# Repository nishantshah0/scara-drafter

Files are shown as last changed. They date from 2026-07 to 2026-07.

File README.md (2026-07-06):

# SCARA Drafter — a robot arm that draws CAD drawings

A 3D-printed SCARA robot arm that picks up a pen and drafts real CAD drawings
(DXF files exported straight from Onshape) onto A5 paper. Design a part in
CAD → hit export → a robot you built draws it in ink.

Built as a mechatronics internship portfolio piece. ~$160 CAD in parts;
every structural component printed on a Bambu P1S.

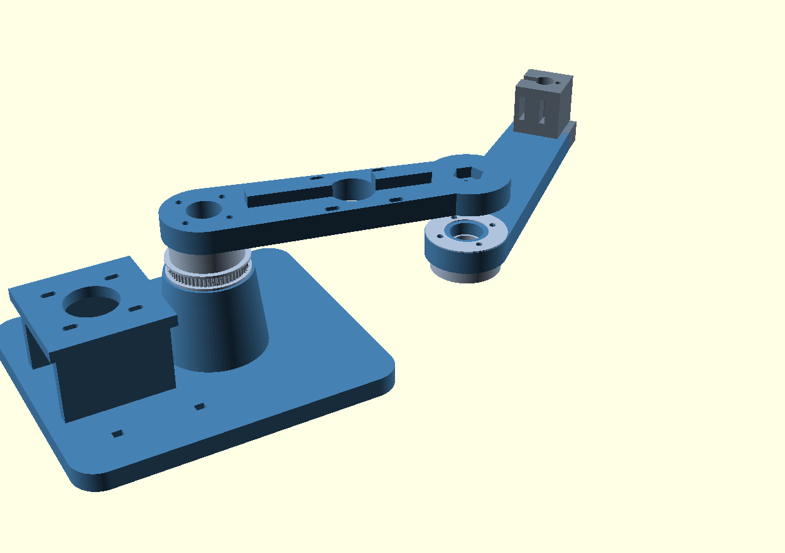
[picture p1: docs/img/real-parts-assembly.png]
Printable parts v1, assembled

*Printable parts v1 (OpenSCAD, [source](cad/scara-parts.scad)): base with shoulder tower
and motor platform, 60T pulley-hubs, both links, pen carriage. Belt center distance is
parametric pending measured belts (D9); tolerances pending the bearing coupon.*

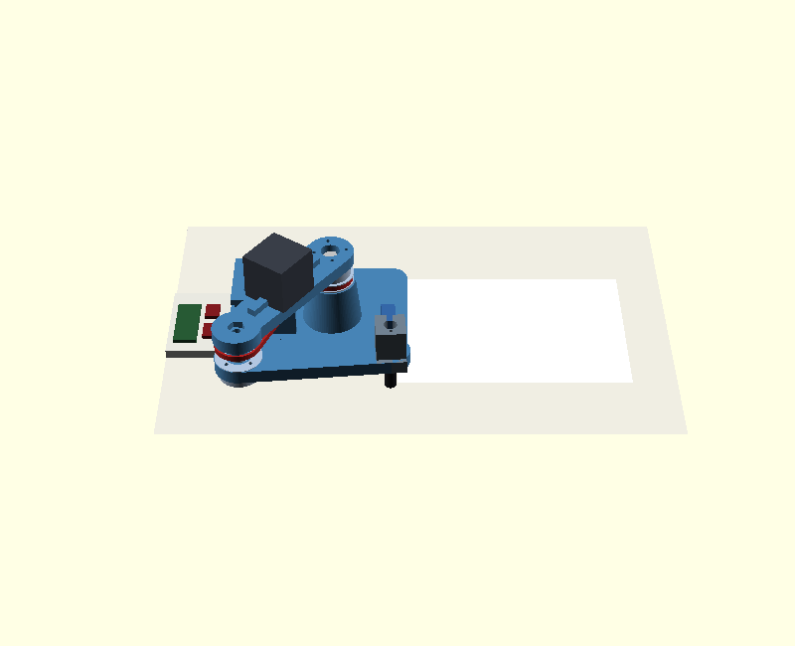
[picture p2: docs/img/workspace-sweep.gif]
Full workspace sweep, arm2/tower collision check

*Animated sweep across the entire usable A5 sheet (32 poses, real inverse-kinematics
solutions from [software/ik.py](software/ik.py) — not hand-picked). Verifies arm2 never
clips the base tower: [clearance_check.py](cad/clearance_check.py) computes the worst
case numerically (pen at the paper's near edge, arm folded to 156°) at **12 mm of
clearance**, run it yourself with `python cad/clearance_check.py`.*

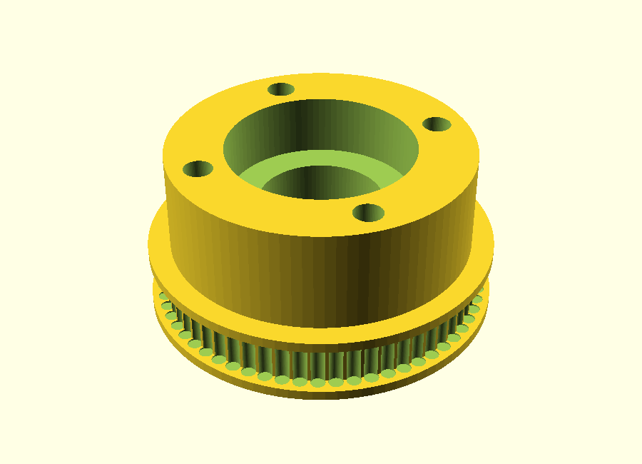
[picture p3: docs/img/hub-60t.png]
60T pulley-hub

*The heart of both joints: printed 60T GT2 pulley integrated with the bearing hub —
one part, printed twice, flipped for the elbow.*

## The demo loop

```
Onshape sketch ──export──▶ DXF ──parse──▶ toolpath ──inverse kinematics──▶
joint angles ──WiFi──▶ Pico W ──step pulses──▶ steppers ──belts──▶ pen on paper
```

Every arrow in that pipeline is something I built and can explain.

## Architecture

- **Topology:** SCARA — two rigid printed links swinging in a horizontal
  plane (gravity stays out of the drawing plane; precision comes cheaper),
  plus a micro-servo pen lift. ~130 mm links → covers an A5 sheet.
- **Actuation:** 2× NEMA17 steppers through printed GT2 belt reductions
  (~3:1) — reduction multiplies resolution and torque, and belt tension is
  the main precision tuning knob.
- **Brains, split in two:** the PC does the thinking (DXF parsing, path
  planning, IK — Python), the Pico W does the doing (real-time step pulse
  generation, limits, fail-safe stop). Same distributed pattern as my
  [slam-rover design study](https://github.com/nishantshah0/slam-rover).
- **Calibration philosophy:** the arm draws a test square, I measure it with
  calipers, software corrects the model — repeat until a 50 mm square is a
  50 mm square. Measured, not assumed.

## Build phases

| Phase | Weeks | Deliverable |
|---|---|---|
| 0 — Design & order | 0–1 | Parts ordered; base/links/carriage CAD'd; bearing-fit coupon printed |
| 1 — Electronics bench | 1–2 | Both joints sweeping smoothly under command; pen lift working |
| 2 — Assembly & IK | 2–3 | Arm moves pen to commanded (x, y); first drawn line |
| 3 — Precision | 3–5 | **One clean 50 mm square** (the project's summit — tuning journey logged) |
| 4 — DXF pipeline | 5–6 | Draws a real Onshape-exported drawing. The money demo |
| 5 — Stretch | — | Handwriting mode; whiteboard tile; cycloidal gearbox joints v2 |

Full milestone ladders: [docs/roadmap.md](docs/roadmap.md) ·
Parts: [docs/shopping-list.md](docs/shopping-list.md) ·
Why-decisions: [docs/decisions.md](docs/decisions.md) ·
Failure modes: [docs/risks.md](docs/risks.md) ·
War stories: [docs/debugging-log.md](docs/debugging-log.md)

## Status

Phase 0 complete (July 2026): CAD done (carriage printed & pen-fit verified),
firmware written and host-simulated **9/9**, PC software (IK, planner, DXF
pipeline) written and self-tested **10/10**. Awaiting parts delivery.

Run the tests yourself:
`python firmware/host_test/run_sim.py` · `python software/selftest.py`

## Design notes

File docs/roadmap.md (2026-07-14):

# Roadmap — Milestone Ladders

Working rules (proven on the last project): one variable at a time · bench
before assembly · every milestone demonstrable in minutes · 20-minute fights
get logged · ~8–10 hrs/week.

**THE ONE RULE OF THIS PROJECT:** no resets, no pivots, no new-project
shopping until the arm draws **one clean 50 mm square**. That milestone is
deliberately placed on the far side of the hard part. After it, everything
is downhill and demos.

---

## Phase 0 (Week 0–1) — Design & order

- [ ] Order the [cart](shopping-list.md) (~$160, one order)
- [ ] **Bearing coupon** (print first): pockets for the 608/625 bearings +
      NEMA17 pilot boss + a printed GT2 tooth-profile sample — the tolerance
      test, same method as last project's motor coupon
- [ ] CAD session A: pen carriage (servo lift, pen clamp) — belt-independent,
      safe to finalize pre-arrival
- [ ] CAD session B: printed 60T GT2 pulleys (the big reduction wheels are
      PRINTED, not bought) — verify tooth mesh against the coupon sample
- [ ] **WAIT for the box, then measure:** exact belt lengths and pulleys in
      hand set the joint center-distances → only THEN:
- [ ] CAD session C: base + link 1 + link 2, dimensioned around the real
      belts, with slotted motor mounts for tension adjustment
- [ ] Print base + links

**Done when:** parts arrived, all structure printed around measured parts.
**Predicted fights:** bearing press-fits (the coupon's job) and belt-length
arithmetic (design rule: the belt is bought truth, the CAD adapts to it).

## Phase 1 (Week 1–2) — Electronics bench

**Pre-flight notes (final hand-audit, 2026-07-05):**
- Motor hookup reality: with drivers seated in the breadboard, the motor's
  4-pin plug connects via **four short M-M jumpers** from the driver's
  motor-pin rows — keep them short and direct, never through the long rails
  (R8 refined).
- BTT TMC2209 defaults to 1/8 microstepping standalone → **jumper MS1+MS2
  to 3V3** for 1/16 (or set via UART later). Works either way; 1/16 doubles
  resolution for free.
- EN pin is **active-LOW** (low = motors on). Firmware drives it HIGH to
  kill motion — wired to GP6, handled in firmware.
- **Not in the cart:** 2× 100 µF (16 V+) electrolytic capacitors for the
  drivers' 12 V pins — grab from any electronics counter/kit (~$3). Build
  can start without them (short, direct 12 V leads) but add them before
  long runs.
- The Pico W uses a **micro-USB** cable (not USB-C) — check the drawer.
- **Watch for Pico resets when the servo moves.** VBUS is a raw USB
  pass-through, not a regulated rail — an MG90S stall spike (several
  hundred mA) could sag it enough to brown out the Pico mid-job. Pen-lift
  is light duty so it's likely fine, but if `main.py` reboots (watch for
  "fw ready" reappearing) exactly when `P 1`/`P 0` fires, that's the cause.
  Fix: add a 100 µF cap across the servo's power pins (from the capacitor
  kit), or move servo power off VBUS onto its own small 5V regulator fed
  from the 12V rail.

Need to understand first: how steppers work (magnetic gear-teeth counting — position without
encoders), microstepping, driver current limiting (the multimeter ritual),
why 12 V logic needs level-separated wiring.

- [ ] Pico blinks (hello-world ritual)
- [ ] One stepper spins on the bench (driver current set FIRST — multimeter)
- [ ] Smooth acceleration ramps (step-generation core already written; jerky
      starts = skipped steps = lost position)
- [ ] Both joints sweep to commanded angles, repeatably
- [ ] Pen servo lifts/drops on command
- [ ] Fail-safe: commands stop → motion stops (watchdog pattern, again)

**Done when:** "joint 1 to 45°, joint 2 to −30°" just works, every time.

## Phase 2 (Week 2–3) — Assembly & IK

The whiteboard afternoon: derive two-link inverse kinematics from scratch
(law of cosines, atan2 — I want to own this math cold; it's interview bait).

- [ ] Arm assembled: bearings seated, belts tensioned, zero slop by hand
- [ ] Homing routine (arm finds its zero position)
- [ ] IK implemented: command (x, y) in mm → pen goes there
- [ ] Dot grid test: pen taps a 5×5 grid — do the dots land where math says?
- [ ] **First drawn line** 📸

**Done when:** a commanded straight line is recognizably straight.
**Predicted fights:** mirrored motion (sign error), degrees/radians (again),
elbow-up vs elbow-down solution flip mid-move.

## Phase 3 (Week 3–5) — Precision. The valley.

Draw 50 mm test square → measure with calipers → diagnose → adjust → again.
Expect 3–6 loops. Improvements come in millimeters. **This phase is the
project** — the before/after square photos are the single best interview
artifact this build produces.

- [ ] Square v1 drawn + measured (it will be bad — log it, keep it)
- [ ] Backlash measured and software-compensated
- [ ] Belt tension tuned; joints reprinted if flexing
- [ ] Corner overshoot fixed (acceleration tuning)
- [ ] **One clean square: sides 50±0.5 mm, corners meet** 🏔️

**Done when:** the square. Frame the v1-vs-final photos side by side.

## Phase 4 (Week 5–6) — The DXF pipeline

- [ ] Python DXF parser (lines + arcs + circles from Onshape exports)
- [ ] Path planner: pen-up travel ordering, feedrates
- [ ] Draw a simple exported sketch (the coupon drawing is poetic)
- [ ] **Money demo:** design a part live in Onshape, export, arm drafts it 📹

## Phase 5 (Stretch, whenever)

- Handwriting/single-line fonts (it signs your name)
- Dry-erase whiteboard tile (infinite career-fair demos)
- Cycloidal gearbox joints v2 (the mechanical deep-cut)
- Pen → gripper swap experiments

## Portfolio artifacts to collect

Phase 0: CAD renders · Phase 2: first-line photo · Phase 3: the
square-evolution series (v1 → final) · Phase 4: the full-loop video
(Onshape screen → arm drawing → finished page) · Throughout: debugging log.

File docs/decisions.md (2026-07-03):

# Design Decisions

## D1 — SCARA topology, not articulated arm

Drawing punishes wobble: every micron of slop is visible ink. A SCARA keeps
both links swinging in the horizontal plane, so gravity never bends the arm
into the page and rigidity is a 2D problem. Also: SCARA is a named industrial
robot class (fast assembly arms) — the term carries weight. Articulated
(shoulder-lifts-against-gravity) arms need stronger joints for zero drawing
benefit here.

## D2 — Link lengths 130 mm / 130 mm → A5 canvas

Reach vs rigidity: longer links = bigger paper but more flex and amplified
joint slop. 130+130 comfortably covers A5 (148×210). The base is designed so
longer v2 links can bolt on later (same upgrade-path philosophy as the
rover's spare-hole grid). Start stiff, earn reach.

## D3 — NEMA17 steppers + TMC2209 through ~3:1 printed belt reduction

Steppers give exact position without encoders (they move in fixed steps).
TMC2209 drivers: silent, breadboard-plugging, current set by one screw.
The 3:1 GT2 belt reduction triples angular resolution (~0.03°/microstep at
the joint) and torque, and adds the tension adjustment that Phase 3 tuning
lives on. Hobby servos were rejected: jittery, no microstepping, sloppy.

## D4 — Brains split: PC plans, Pico executes

DXF parsing, path planning, and IK run in Python on the PC (easy to write,
debug, and demo). The Pico W receives compact motion segments over WiFi/USB
and generates precisely-timed step pulses (the hard-real-time part). This is
the standard industrial pattern (planner ↔ motion controller), and it reuses
the fail-safe watchdog + UDP protocol design from the slam-rover firmware.

## D8 — Power architecture: 12 V for motors only; USB powers everything else

This is a desk machine that's PC-connected by design (the PC is the planner),
so the Pico + pen servo run off USB the whole project — no buck converter,
no battery. The 12 V supply touches ONLY the driver motor rails. Two rules:
12 V never routes near a Pico pin, and **motor coil current never flows
through breadboard rails** — the motor's 4-pin cable plugs directly onto the
driver's inline motor pins (breadboards handle signals fine but sag/heat at
amp-level currents). Driver current set to ~0.8 A RMS: gentle on wiring,
and the 3:1 reduction means torque margin stays ~3× anyway.

## D9 — Belt-first design rule

Closed-loop GT2 belts come in fixed lengths (e.g. 2GT-200 = 100 teeth); the
20T motor pulleys are bought but the 60T joint pulleys are PRINTED. Center
distance between motor and joint is therefore dictated by belt + pulley
geometry — so link/base CAD is dimensioned AFTER the belts are in hand and
measured. The purchased belt is ground truth; the CAD adapts to it, never
the reverse. (Slotted motor mounts give ±3 mm of tension adjustment around
the computed center distance.)

## D5 — Pen lift: micro servo, gravity-down

MG90S rotates a cam that lifts the pen; pen weight + a light spring gives
consistent down-force. Simplest mechanism that yields consistent line width.

## D6 — No-solder constraint carried over

Every connection: breadboard, dupont, screw terminal. Drivers bought
pre-soldered; PSU gets a screw-terminal barrel adapter. One deliberate
exception allowed if unavoidable: a 10-minute makerspace soldering favor
rather than a redesign.

## D7 — Calibration: measure-and-correct, never trust the model

The kinematic model (link lengths, zero angles, backlash) is treated as
wrong until proven: draw test square → measure with calipers → fit
corrections in software → repeat. Same philosophy as the print-tolerance
coupon. Accuracy target: 50 mm square at ±0.5 mm with corners meeting.

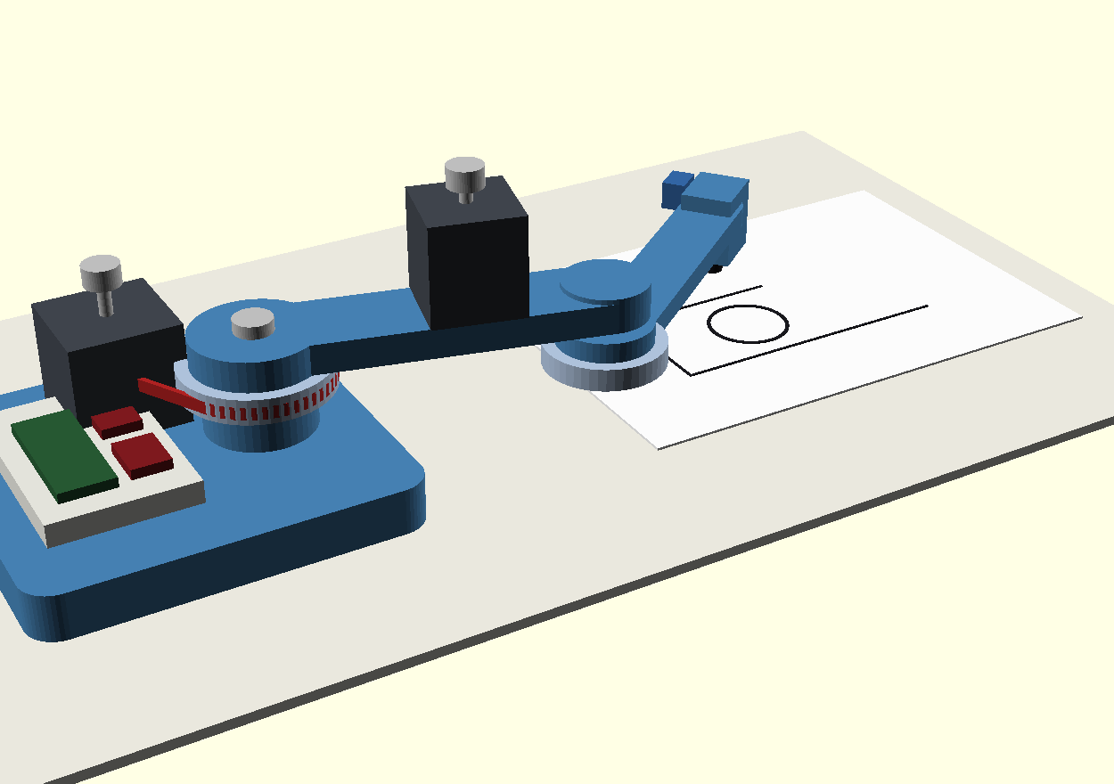
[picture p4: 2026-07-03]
docs/img/concept-render.png

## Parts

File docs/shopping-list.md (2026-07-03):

# Shopping List — one order, ~$160 CAD

Amazon.ca unless noted. Rules carried over from the last project: fast
shipping on everything; no soldering anywhere (buy the exact variants noted);
prices approximate.

| Item | Spec — what the listing MUST say | ~CAD |
|---|---|---|
| 2× NEMA17 stepper motors | "NEMA 17", ~40 mm body, 1.5–1.8 A (e.g. 17HS4401). Often sold in 2/3-packs | $32 |
| 2× TMC2209 driver modules | "TMC2209" stepstick, **pins pre-soldered** (BIGTREETECH-style are; check photos). TMC = silent + easy current setting | $18 |
| Raspberry Pi Pico WH | pre-soldered headers, WiFi | $13 |
| 12 V 3 A power supply | barrel jack + **screw-terminal adapter** included | $22 |
| GT2 belt + pulleys kit | "GT2 6mm belt + 20T pulleys" kit — must include **2× closed-loop belts (200 mm / 2GT-200)** and **2× 20T pulleys, 5 mm bore** (grub screws + allen key usually included). The big 60T pulleys are NOT bought — they're printed (D9) | $18 |
| Bearings | **608ZZ (8×22×7) ×4** — skateboard bearings; both joints use the identical stack (one pattern, built twice) | $10 |
| 2× M8×50 hex bolts + nyloc nuts | the joint axles the bearings ride on — Amazon assortment or any hardware store ($3) | $4 |
| MG90S micro servo | metal gear, for the pen lift | $6 |
| Jumper wires + breadboard | M-M and M-F dupont kit + half-size breadboard | $15 |
| M3 screw + nut assortment | 8–20 mm lengths; arms genuinely need screws (zip ties flex) | $10 |
| Electrolytic capacitors 100 µF | often included with driver kits — check before buying separately | $6 |
| Fine-liner pens | whatever's in the drawer; Staedtler/Micron if buying | $0–8 |
| **All structure** — base, links, carriage, reductions | **printed, P1S** | $0 |
| **Total** | | **~$155–165** |

## Tools

- **Multimeter — required this time, not borrowable-later:** setting driver
  current (the "Vref ritual") happens before any motor turns, and it's a
  live-voltage measurement. Borrow from the makerspace for week 1 or buy ($18).
- **Calipers — the precision phase runs on them (~$15 digital).** Measuring
  the test square with a ruler wastes the whole exercise. This is the one new
  tool purchase I'd call mandatory.

## Vet-at-checkout traps

1. **TMC2209 with unsoldered pins** — some budget listings ship pins loose.
   Photos show the truth. (Fallback: one 10-minute makerspace visit, but
   let's just buy the right listing.)
2. **NEMA17 "pancake" motors** (20 mm thin ones) — weaker; get ~40 mm bodies.
3. **12 V supply without the screw-terminal barrel adapter** — that $2
   adapter is what keeps this build solder-free.

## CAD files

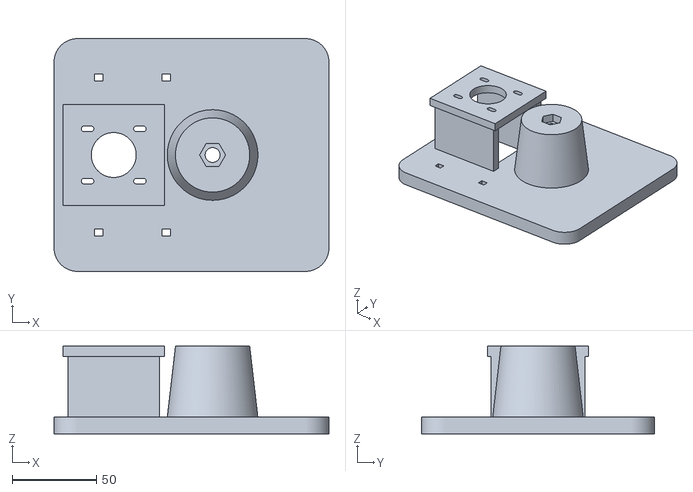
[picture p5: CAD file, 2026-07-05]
cad/base.stl
163.0 x 138.0 x 52.0

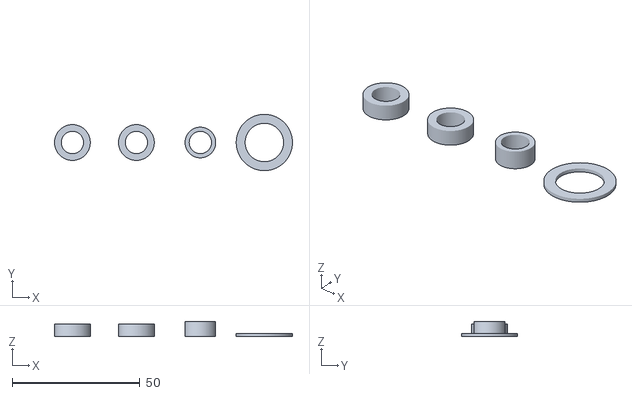
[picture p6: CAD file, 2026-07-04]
cad/spacers.stl
93.0 x 22.0 x 6.00

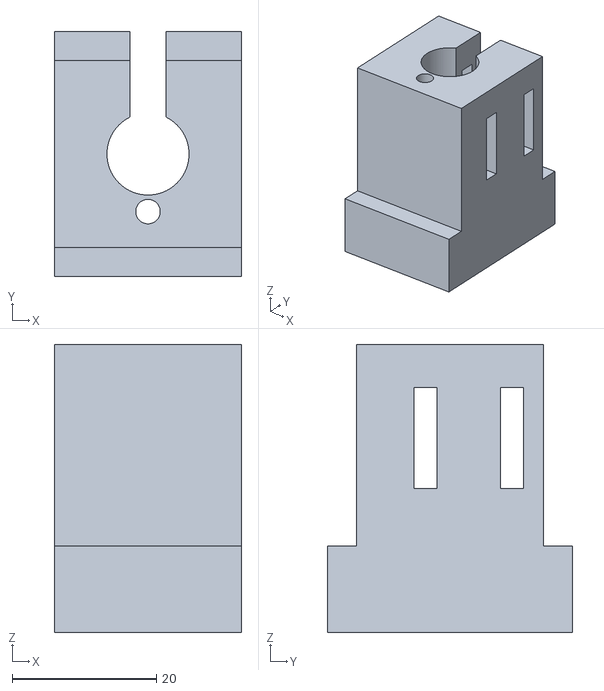
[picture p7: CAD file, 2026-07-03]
cad/carriage.stl
26.0 x 34.0 x 40.0

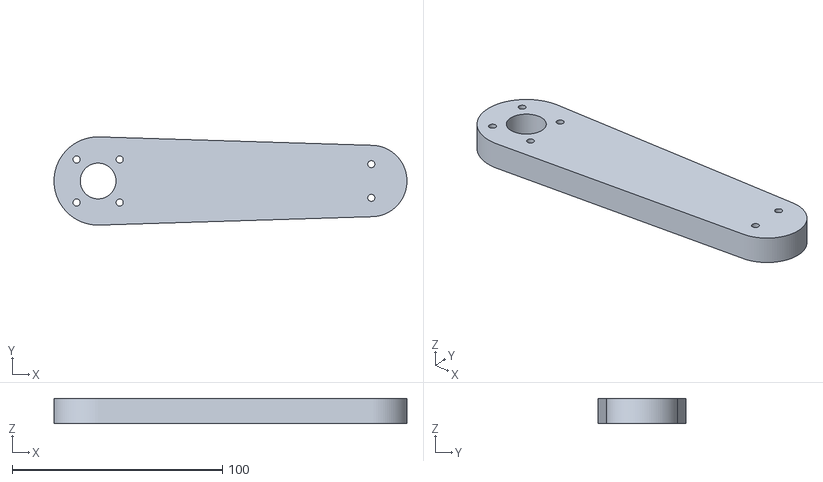
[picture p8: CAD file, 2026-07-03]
cad/arm2.stl
168.0 x 42.0 x 12.0

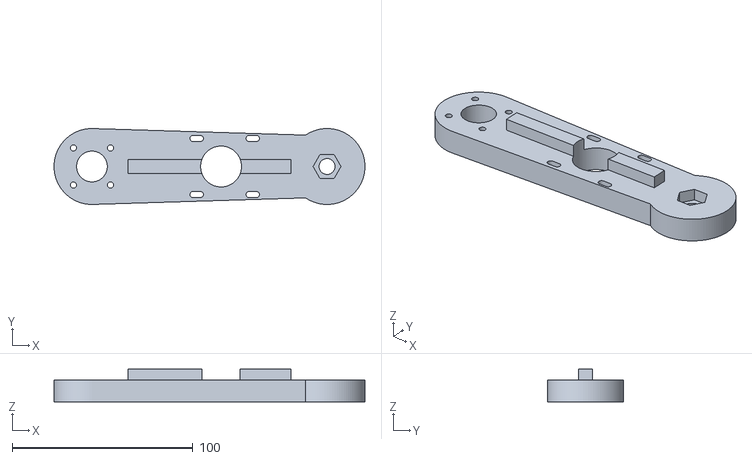
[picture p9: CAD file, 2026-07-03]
cad/arm1.stl
172.0 x 42.0 x 18.0

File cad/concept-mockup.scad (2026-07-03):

// SCARA Drafter — visual concept mockup (proportions real, details simplified)
$fn = 48;

PRINTED = "SteelBlue"; PRINTED2 = "LightSteelBlue"; MOTOR = [0.25,0.27,0.3];
BELT = "Firebrick"; STEEL = "Silver"; PAPER = "White"; INK = [0.1,0.1,0.12];

module rounded_bar(l, w, h) {
    hull() { cylinder(d=w, h=h); translate([l,0,0]) cylinder(d=w, h=h); }
}
module belt_band(l, d1, d2, z, h=5) {
    color(BELT) translate([0,0,z]) difference() {
        hull() { cylinder(d=d1, h=h); translate([l,0,0]) cylinder(d=d2, h=h); }
        translate([0,0,-1]) hull() { cylinder(d=d1-4, h=h+2); translate([l,0,0]) cylinder(d=d2-4, h=h+2); }
    }
}
module motor(s=42, hsh=12) {
    color(MOTOR) translate([-s/2,-s/2,0]) cube([s,s,40]);
    color(STEEL) translate([0,0,40]) cylinder(d=5, h=hsh+8);
    color(STEEL) translate([0,0,40+hsh]) cylinder(d=14, h=8);  // 20T pulley
}

// ---------------- table & paper -------------------------------------------
color([0.93,0.92,0.88]) translate([-140,-130,-4]) cube([500,290,4]);
color(PAPER) translate([130,-64,0]) cube([210,148,1]);
// a half-drawn CAD sketch on the paper (ink)
color(INK) translate([170,-25,1.01]) cube([120,1.2,0.4]);
color(INK) translate([170,25,1.01]) cube([70,1.2,0.4]);
color(INK) translate([170,-25,1.01]) cube([1.2,50,0.4]);
color(INK) translate([215,0,1.01]) difference(){cylinder(d=34,h=0.5);translate([0,0,-0.2])cylinder(d=31,h=1);}

// ---------------- base ------------------------------------------------------
color(PRINTED) hull() {
    translate([-95,-55,0]) cylinder(r=12, h=18);
    translate([ 25,-55,0]) cylinder(r=12, h=18);
    translate([-95, 55,0]) cylinder(r=12, h=18);
    translate([ 25, 55,0]) cylinder(r=12, h=18);
}
// electronics on the base tray
color([0.9,0.9,0.87]) translate([-92,-40,18]) cube([55,80,9]);          // breadboard
color([0.15,0.35,0.2]) translate([-84,-30,27]) cube([21,52,4]);         // Pico
color([0.5,0.1,0.12]) translate([-58,-28,27]) cube([15,20,4]);          // driver 1
color([0.5,0.1,0.12]) translate([-58,2,27]) cube([15,20,4]);            // driver 2
// shoulder motor (slotted mount region)
translate([-42,34,18]) motor();
// shoulder tower
color(PRINTED) cylinder(d=42, h=34);

// ---------------- shoulder joint + link 1 ----------------------------------
rotate([0,0,-14]) {
    // hub = printed 60T pulley
    color(PRINTED2) translate([0,0,34]) cylinder(d=58, h=10);
    color(PRINTED)  translate([0,0,44]) cylinder(d=48, h=12);
    color(STEEL)    translate([0,0,56]) cylinder(d=15, h=5);   // nyloc
    // link 1 body
    color(PRINTED) translate([0,0,44]) rounded_bar(130, 34, 12);
    // elbow motor riding link 1
    translate([78,0,56]) rotate([0,0,90]) motor(s=36, hsh=6);
    // elbow tower on link1 end
    color(PRINTED) translate([130,0,44]) cylinder(d=34, h=14);

    // ---------------- elbow joint + link 2 ---------------------------------
    translate([130,0,0]) rotate([0,0,52]) {
        color(PRINTED2) translate([0,0,24]) cylinder(d=48, h=9);   // 60T hub
        color(PRINTED)  translate([0,0,33]) cylinder(d=38, h=8);
        color(STEEL)    translate([0,0,41]) cylinder(d=13, h=4);
        color(PRINTED)  translate([0,0,24]) rounded_bar(130, 26, 9);
        // pen carriage
        color(PRINTED) translate([120,-11,10]) cube([26,22,30]);
        color([0.2,0.4,0.65]) translate([133,14,26]) cube([14,10,12]); // servo
        color(INK) translate([133,0,1]) cylinder(d=9, h=30);           // pen
        color(INK) translate([133,0,0.5]) cylinder(d1=2, d2=9, h=6);
    }
}
// shoulder belt (motor1 -> shoulder hub), drawn in base frame
translate([0,0,0]) {
    b1l = norm([-42-0, 34-0]);
    rotate([0,0,atan2(34,-42)]) belt_band(b1l, 58, 16, 36);
}

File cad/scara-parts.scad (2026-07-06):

// ===== SCARA Drafter — real printable parts, v1 ============================
// Render one part:   openscad -D 'PART="hub"' -o hub.stl scara-parts.scad
// Parts: "base" "arm1" "arm2" "hub" (print 2) "carriage" "spacers" "assembly"
//
// D9 NOTE: CD (motor<->joint center distance) is computed for a 2GT-200
// closed belt + 20T/60T. VERIFY against the real belts, adjust, re-render.
// Tolerances (+0.2/+0.3) are first guesses — the bearing coupon refines them.

PART = "assembly";
$fn = 96;

// ---- key parameters --------------------------------------------------------
LINK       = 130;     // joint-to-joint arm length
CD         = 58.6;    // belt center distance (2GT-200, 20T:60T) — MEASURE (D9)
ARM_T      = 12;      // arm bar thickness
ARM_W      = 34;      // arm bar width
T60_N      = 60;      // printed pulley teeth
HUB_BOSS_H = 12;      // arm-mounting boss height
PUL_H      = 8;       // belt section height
// 608 pocket, tuned PER SIDE — FDM prints commonly come out tighter near
// the bed (bottom pocket) than higher up in the same print (top pocket).
// 2026-07-06 bench test: bottom snug, top wiggled loose -> shaved 0.2mm.
BRG_OD_BOT = 22.3;    // bottom pocket (near the bed)
BRG_OD_TOP = 22.1;    // top pocket (near the arm boss) — shrink further if still loose
BRG_H      = 7.2;
AXLE_D     = 8.8;     // M8 clearance
HEXAF     = 13.4;     // M8 bolt-head / nut hex across-flats + tol
M3         = 3.4;
BC         = 29;      // bolt circle for arm<->hub (4x M3)
TOWER_H    = 52;      // shoulder tower height (sets belt plane)
NEMA       = 42.3;    // NEMA17 body + tol
NEMA_HOLES = 31;      // NEMA17 mounting square
NEMA_BOSS  = 22.6;    // NEMA17 pilot boss clearance
PEN_D      = 11.0;    // MUJI gel knock-type 0.5 — MEASURE the barrel at its
                      // widest gripped point and set this to measured + 0.4.
                      // The flex slit takes up the slack; clip rides in the slit.

// GT2 60T geometry
function pitch_d(n) = 2*n/PI;
T60_OD = pitch_d(T60_N) - 0.5;             // ~37.7

module m3_ring() { for (a=[45:90:360]) rotate([0,0,a]) translate([BC/2,0,-1]) cylinder(d=M3, h=99); }

// ---- GT2 pulley section ----------------------------------------------------
module gt2_60(h) {
    difference() {
        union() {
            translate([0,0,1.2]) cylinder(d=T60_OD, h=h-2.4);
            cylinder(d=T60_OD+3.6, h=1.2);                       // bottom flange (on the bed)
            // top flange with 45-degree cone underneath: self-supporting,
            // no ring overhang (print-failure lesson, debugging log 2026-07-03)
            translate([0,0,h-3.0]) cylinder(d1=T60_OD, d2=T60_OD+3.6, h=1.8);
            translate([0,0,h-1.2]) cylinder(d=T60_OD+3.6, h=1.2);
        }
        for (i=[0:T60_N-1]) rotate([0,0,i*360/T60_N])
            translate([T60_OD/2+0.25, 0, 1.0])
                cylinder(d=1.7, h=h-2.0);                        // tooth grooves
    }
}

// ---- HUB (print 2 — shoulder boss-up, elbow: same part flipped) ------------
module hub() {
    difference() {
        union() {
            gt2_60(PUL_H);
            translate([0,0,PUL_H]) cylinder(d=36, h=HUB_BOSS_H); // arm boss
        }
        translate([0,0,-1]) cylinder(d=BRG_OD_BOT, h=BRG_H+1);   // bottom brg pocket ↓ (printed near the bed — usually the snug one)
        // FULL 45° cone above the pocket — zero flat, zero bridging. The
        // bearing gets its flat seat from a drop-in printed washer instead
        // (in spacers.stl). Second iteration of the ring-bridge lesson.
        translate([0,0,BRG_H-0.01]) cylinder(d1=BRG_OD_BOT, d2=AXLE_D+6, h=(BRG_OD_BOT-(AXLE_D+6))/2);
        translate([0,0,PUL_H+HUB_BOSS_H-BRG_H]) cylinder(d=BRG_OD_TOP, h=BRG_H+1);  // top pocket (printed higher up — usually the loose one; tune separately)
        cylinder(d=AXLE_D+6, h=99, center=true);                 // inner clear
        m3_ring();                                               // arm bolts
        for (a=[45:90:360]) rotate([0,0,a]) translate([BC/2,0,PUL_H+1.5])
            cylinder(d=6.6, h=3, $fn=6);                         // M3 nut pockets
    }
}

// ---- ARM (shared shape) -----------------------------------------------------
module arm_blank(len, hub_end_d) {
    hull() {
        cylinder(d=hub_end_d, h=ARM_T);
        translate([len,0,0]) cylinder(d=ARM_W, h=ARM_T);
    }
}

// ARM 1: bolts to shoulder hub; carries elbow axle + motor 2 (shaft-down)
module arm1() {
    difference() {
        union() {
            arm_blank(LINK, 42);
            translate([LINK,0,0]) cylinder(d=42, h=ARM_T);
            // rib
            translate([20,-4,ARM_T]) cube([LINK-40,8,6]);
        }
        translate([0,0,-1]) cylinder(d=17, h=99);                // spacer/nyloc access
        m3_ring();                                               // to shoulder hub
        // elbow axle: hex head pocket on TOP, shaft hangs down
        translate([LINK,0,0]) {
            cylinder(d=AXLE_D, h=99, center=true);
            translate([0,0,ARM_T-5.8]) cylinder(d=HEXAF/cos(30), h=6, $fn=6);
        }
        // motor 2: face bolts to arm underside, shaft down through arm
        translate([LINK-CD,0,0]) {
            cylinder(d=NEMA_BOSS, h=99, center=true);
            for (x=[-1,1], y=[-1,1]) translate([x*NEMA_HOLES/2, y*NEMA_HOLES/2, -1])
                hull() { cylinder(d=M3, h=99); translate([4,0,0]) cylinder(d=M3, h=99); } // tension slots
        }
    }
}

// ARM 2: bolts under elbow hub; carries the pen carriage
module arm2() {
    difference() {
        arm_blank(LINK, 42);
        translate([0,0,-1]) cylinder(d=17, h=99);
        m3_ring();
        for (y=[-8,8]) translate([LINK,y,-1]) cylinder(d=M3, h=99); // carriage bolts
    }
}

// ---- BASE -------------------------------------------------------------------
module base() {
    difference() {
        union() {
            hull() for (x=[-80,55], y=[-55,55])                  // deck
                translate([x,y,0]) cylinder(r=14, h=10);
            cylinder(d1=56, d2=44, h=TOWER_H);                   // shoulder tower
            // motor platform: shelf at z=TOWER_H-6, motor hangs beneath, shaft up
            translate([-CD,0,0]) {
                for (y=[-28,22]) translate([-27,y,0]) cube([54,6,TOWER_H]);  // 44mm gap: NEMA fits
                translate([-30,-30,TOWER_H-6]) cube([60,60,6]);
            }
        }
        translate([-CD,0,0]) translate([-22,-22,-1]) cube([44,44,13]);  // deck cutout: motor body passes through
        // shoulder axle: hex pocket at tower TOP (bolt head recessed, shank up
        // through the hub stack — an M8x50 reaches; bottom-pocketed it would
        // need M8x90. Caught in final hand-audit 2026-07-05.)
        cylinder(d=AXLE_D, h=99, center=true);
        translate([0,0,TOWER_H-6]) cylinder(d=HEXAF/cos(30), h=7, $fn=6);
        translate([-CD,0,0]) {
            translate([0,0,TOWER_H-8]) cylinder(d=NEMA_BOSS+4, h=10);   // shaft/boss hole
            for (x=[-1,1], y=[-1,1]) translate([x*NEMA_HOLES/2+ -2, y*NEMA_HOLES/2, TOWER_H-8])
                hull() { cylinder(d=M3, h=10); translate([4,0,0]) cylinder(d=M3, h=10); }
        }
        // electronics tray zip slots
        for (x=[-70,-30], y=[-48,44]) translate([x,y,-1]) cube([5,4,12]);
    }
}

// ---- PEN CARRIAGE -----------------------------------------------------------
module carriage() {
    difference() {
        union() {
            cube([26,34,ARM_T]);                                 // mount foot
            translate([0,4,0]) cube([26,26,40]);                 // pen block
        }
        for (y=[9,25]) translate([13,y,-1]) cylinder(d=M3, h=99); // to arm2
        translate([13,17,-1]) cylinder(d=PEN_D+0.4, h=99);       // pen bore (see PEN_D)
        translate([13-2.5,17,-1]) cube([5,20,99]);               // flex-grip slit (also clears the clip)
        translate([-1,12,20]) cube([28,3.2,14]);                 // zip slots: servo
        translate([-1,24,20]) cube([28,3.2,14]);
    }
}

// ---- SPACERS ----------------------------------------------------------------
module spacers() {
    // print ONE SET PER JOINT (2 sets total)
    difference() { cylinder(d=14, h=5);   cylinder(d=8.7, h=99, center=true); }  // top spacer (above top bearing race)
    translate([25,0,0])
    difference() { cylinder(d=14, h=5);   cylinder(d=8.7, h=99, center=true); }  // bottom spacer (tower/arm1 to lower race — keeps hub off the tower)
    translate([50,0,0])
    difference() { cylinder(d=12, h=6.0); cylinder(d=8.7, h=99, center=true); }  // inner tube (between the two bearing inner races)
    translate([75,0,0])
    difference() { cylinder(d=22.0, h=1.2); cylinder(d=15, h=99, center=true); } // seat washer: drops into the lower pocket, gives the bearing a flat face against the cone
}
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

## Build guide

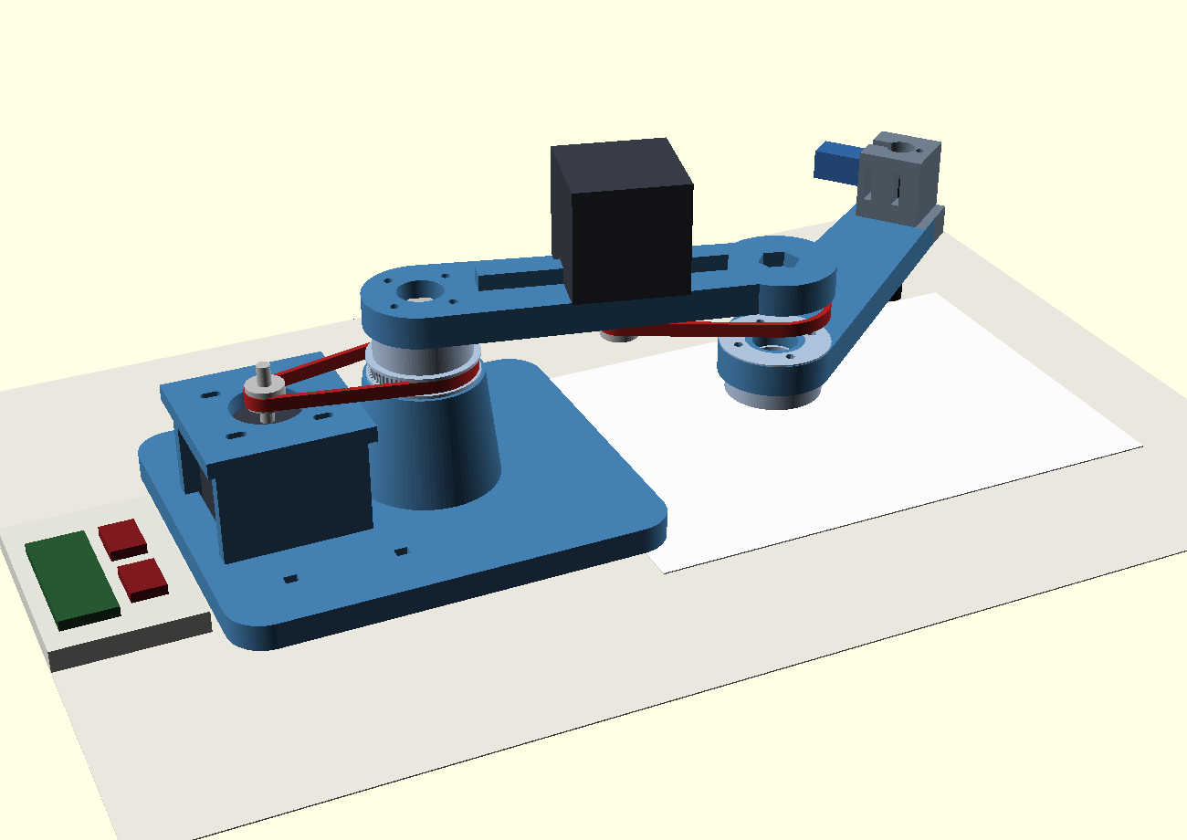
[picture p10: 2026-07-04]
docs/img/assembly-components.png

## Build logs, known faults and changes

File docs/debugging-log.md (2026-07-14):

# Debugging Log

What broke, why, and how it was fixed. Written for future-me and for
interviews ("tell me about a hard problem"). The Phase 3 square-tuning
saga belongs here, measurement by measurement.

## Entry template

```markdown
## YYYY-MM-DD — Title

**Phase:** 0–5
**Symptom:** what was observed
**Expected:** what should have happened
**Investigation:** what was checked, in order (dead ends count)
**Root cause:** the actual problem
**Fix:** what resolved it
**Lesson:** one line
```

---

<!-- Entries below, newest first -->

## 2026-07-06 — Servo wouldn't move despite firmware confirmed working

**Phase:** 1 (Bench Day 1, first physical hardware bring-up)
**Symptom:** Firmware ran perfectly (`scara-drafter fw ready`, `P 1`/`P 0` both
replied `ok` every time, no crashes) — but the physical servo never moved.
**Expected:** Servo snaps to position on `P 1`, back on `P 0`.
**Investigation, in order:**
1. Checked firmware logic — clean, 7+ consecutive `ok` replies, ruled out.
2. Suspected VBUS brownout (a known risk from the roadmap) — no unexpected
   reboots occurred, ruled out.
3. Measured voltage between the wire believed to be VBUS and ground at the
   servo connector — read ~0.0–0.2 V. Should have been ~5 V.
4. Tried re-identifying VBUS by counting pins from a photo of the breadboard
   — counting from a photo turned out to be unreliable (easy to miscount or
   misjudge board orientation).
5. Suspected a dead breadboard row — tested with the multimeter's
   **continuity mode** (beeps when two points are electrically connected).
   Rows beeped fine — breadboard itself was good.
6. Tested continuity between the "VBUS" wire and the actual Pico pin sitting
   in that row — it beeped. So the wire *was* making good contact... just
   with the wrong pin.
**Root cause:** Misidentified which physical pin was VBUS, from counting
breadboard rows off a photo. The wiring itself was solid; the target pin was
wrong.
**Fix:** Re-anchored on a hardware fact instead of a photo-based count: VBUS
is *always* the pin physically closest to the USB connector. Rewired power
to that pin, confirmed live with the multimeter (~5 V), signal wire found by
trial-and-error (move one pin, test `P 1`, repeat) rather than counting.
**Lesson:** For physical wiring, trust *measurement* over *counting from a
photo* — a multimeter's continuity mode can prove a connection is solid
without ever proving it's the *right* connection. When counting is
unreliable, anchor on a physical landmark (like "closest pin to the
connector") instead, and verify live before trusting it.

## 2026-07-03 — Hub bearing seat printed stringy (internal ring bridge)

**Phase:** 0 (first hub print)
**Symptom:** The ceiling of the hub's lower bearing pocket — the flat ring
where the 608's outer race seats — came out drooped and stringy.
**Expected:** A flat, clean seating face.
**Investigation:** Location pinpointed it: the transition from the Ø22.3
pocket to the Ø14.8 central bore is a flat annular surface printed entirely
over air. Straight bridges stretch plastic between two anchored ends; a
*ring* bridge has no straight anchored path, so it sags. Design bug, not a
printer or slicer problem.
**Root cause:** CAD asked the printer for an unsupported internal circular
bridge.
**Fix:** Redesigned the transition: 1 mm flat seat ring (short bridges are
fine) + 45° cone the rest of the way — cones self-support. Hub STL
re-exported; part reprinted.
**Lesson:** Every internal horizontal surface in CAD is a question: "what
does the printer stand on here?" Flat ring ceilings over voids = automatic
fail. Chamfer or step them at design time.

**Round 2 (same day):** Reprint with the partial chamfer STILL stringy — in
two places. (a) The 1 mm flat "seat ring" I'd kept was itself built on chord
bridges spanning the whole pocket, so the disease survived my first fix;
(b) the TOP BELT FLANGE is also a ring overhang (1.8 mm cantilevered over
air + the tooth grooves) — same failure mode, different location, only
spotted on the reprint. Second-iteration fix: bottom transition is now a FULL cone (zero
flat, zero bridging) with a drop-in printed seat washer restoring the
bearing's flat face; top flange got a 45° cone underneath. Revised lesson:
when a failure mode is found once, sweep the WHOLE part for it — I fixed
one instance and shipped two more.

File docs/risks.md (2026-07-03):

# Risk Register

## R1 — Backlash & flex: wobbly lines 🔴 THE BOSS

Printed joints have slop; belts stretch; links flex. All of it becomes
visible squiggle. **Expected, planned for:** Phase 3 exists solely to grind
this down (tension, backlash compensation, joint reprints, acceleration
tuning). Mitigations designed in up front: belt reduction with tensioners,
ribbed links, bearing-fit coupon before any real part prints.

## R2 — IK bugs: arm confidently draws in the wrong place 🟠

Sign errors, degrees-vs-radians, elbow-up/elbow-down solution flips. One bad
evening each, then done. Mitigation: dot-grid test before any drawing; unit
discipline (the Onshape `5mm + #var` lesson lives on).

## R3 — Stepper current misconfigured 🟠

Too low → skipped steps → drawings drift mid-line. Too high → drivers cook.
Mitigation: the Vref ritual with a multimeter BEFORE first motion, per the
TMC2209 datasheet formula. Non-negotiable ordering of operations.

## R4 — Lost steps = silent position loss 🟠

Steppers don't know they missed a step; the arm just believes a lie forever.
Mitigations: acceleration ramps (never jerk from zero), conservative speeds,
homing routine to re-zero between drawings.

## R5 — 12 V power mistakes 🟡

12 V into a 3.3 V pin kills a Pico instantly. Mitigation: 12 V exists ONLY
on the driver motor rails; multimeter polarity check before first power;
never rewire live (rule inherited from the rover plan).

## R6 — The week-4 valley (the human risk) 🔴 REAL TALK

Recent history: three project resets in three days when things stopped being
shiny. Phase 3 of this build is deliberately unglamorous — the arm WORKS but
draws badly, and improvement comes in millimeters. This is where this
project dies if it dies.
**Contract with self: no resets, no new-project browsing until ONE CLEAN
50 mm SQUARE exists.** The milestone is placed just past the valley on
purpose. Reread this paragraph in week 4.

## R8 — Amp-level current through a breadboard 🟠

Breadboard spring contacts are for signals; sustained ~1 A+ makes them heat,
brown, and go intermittent (maddening to debug). Rule (D8): motor cables plug
DIRECTLY onto the driver modules' motor pins; only logic signals and the
capacitor-buffered 12 V feed touch the breadboard; driver current capped at
~0.8 A RMS. Also: 100 µF capacitor sits right at each driver's 12 V pins —
drivers can die from supply voltage spikes without it.

## R7 — Purchasing traps 🟡

Unsoldered driver pins, pancake NEMA17s, PSU without screw adapter — see
shopping-list vet notes. Wrong purchases cost a week of shipping each.

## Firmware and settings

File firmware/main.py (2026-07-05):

# SCARA Drafter — Pico W firmware
#
# Role: the "spinal cord". The PC plans everything (DXF -> paths -> IK ->
# timed segments); this firmware just executes segments with hardware-exact
# timing and fails safe. Protocol = text lines over USB serial:
#
#   PC -> Pico                              reply
#   G <steps1> <steps2> <ms>   queue a coordinated move        "ok <qlen>"
#   P <0|1>                    pen up(0)/down(1)               "ok"
#   E <0|1>                    drivers off(0)/on(1)            "ok"
#   H                          zero both position counters      "ok"
#   X                          ESTOP: flush queue, pen up, off  "ok estop"
#   ?                          status                           "pos <p1> <p2> q <n> pen <0|1>"
#
# Fail-safe: TMC2209 EN is ACTIVE-LOW (low = motors powered). We hold it
# HIGH (off) at boot, and the watchdog forces it HIGH again if the PC goes
# silent mid-queue. A disabled stepper freewheels: the arm just stops.

import sys
import time
import select
from machine import Pin, PWM
from stepper import StepChannel

# ---- pins (matches docs wiring chart) --------------------------------------
STEP1, DIR1 = 2, 3
STEP2, DIR2 = 4, 5
EN_PIN      = 6          # both drivers, ACTIVE-LOW
SERVO_PIN   = 7

# ---- pen servo --------------------------------------------------------------
PEN_UP_US, PEN_DOWN_US = 1900, 1200   # tune at bench (pulse widths)
SETTLE_MS = 250                        # let the pen land before moving

WATCHDOG_MS = 1500

en = Pin(EN_PIN, Pin.OUT, value=1)                    # boot: drivers OFF
servo = PWM(Pin(SERVO_PIN)); servo.freq(50)

def pen(down):
    servo.duty_ns((PEN_DOWN_US if down else PEN_UP_US) * 1000)

pen(False)
j1 = StepChannel(0, STEP1, DIR1)
j2 = StepChannel(1, STEP2, DIR2)

queue = []            # pending (s1, s2, ms) segments
seg_end_ms = 0        # when the running segment completes
running = False
pen_down = False
last_rx = time.ticks_ms()

poller = select.poll()
poller.register(sys.stdin, select.POLLIN)
buf = ""

def readline():
    global buf
    while poller.poll(0):
        ch = sys.stdin.read(1)
        if ch in ("\n", "\r"):
            line, buf = buf, ""
            if line:
                return line
        else:
            buf += ch
    return None

def start_next():
    global running, seg_end_ms
    s1, s2, ms = queue.pop(0)
    n = max(abs(s1), abs(s2), 1)
    # each axis spreads its steps evenly across the same segment duration
    if s1: j1.start_segment(s1, (ms * 1000) // abs(s1))
    if s2: j2.start_segment(s2, (ms * 1000) // abs(s2))
    seg_end_ms = time.ticks_add(time.ticks_ms(), ms)
    running = True

def estop():
    global queue, running, pen_down
    queue = []
    running = False
    pen_down = False
    pen(False)
    en.value(1)

print("scara-drafter fw ready")

while True:
    now = time.ticks_ms()

    line = readline()
    if line:
        last_rx = now
        p = line.split()
        try:
            if p[0] == "G" and len(p) == 4:
                queue.append((int(p[1]), int(p[2]), max(1, int(p[3]))))
                print("ok", len(queue))
            elif p[0] == "P":
                pen_down = p[1] == "1"
                pen(pen_down)
                time.sleep_ms(SETTLE_MS)
                print("ok")
            elif p[0] == "E":
                en.value(0 if p[1] == "1" else 1)   # active-low!
                print("ok")
            elif p[0] == "H":
                j1.position = 0; j2.position = 0
                print("ok")
            elif p[0] == "X":
                estop()
                print("ok estop")
            elif p[0] == "?":
                print("pos", j1.position, j2.position,
                      "q", len(queue) + (1 if running else 0),
                      "pen", 1 if pen_down else 0)
            else:
                print("err")
        except (ValueError, IndexError):
            print("err")

    # segment bookkeeping
    if running and time.ticks_diff(now, seg_end_ms) >= 0 \
            and not j1.busy() and not j2.busy():
        j1.finish_segment(); j2.finish_segment()
        running = False

    if not running and queue:
        start_next()

    # WATCHDOG: PC vanished mid-job -> stop safe
    if (running or queue) and time.ticks_diff(now, last_rx) > WATCHDOG_MS:
        estop()
        print("watchdog estop")

    time.sleep_ms(2)

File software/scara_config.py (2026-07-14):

"""All the numbers that define the machine, in one place.
Calibration (Phase 3) edits THIS file, nothing else."""
import math

# --- geometry (mm) -----------------------------------------------------------
L1 = 130.0            # shoulder -> elbow
L2 = 130.0            # elbow -> pen
PAPER_CX = 120.0      # sheet center, mm in front of shoulder axis
SHEET_W, SHEET_H = 210.0, 148.0   # A5 landscape
MARGIN = 8.0          # keep-out border on the sheet

# --- drivetrain ---------------------------------------------------------------
FULL_STEPS = 200      # 1.8deg motor
MICROSTEP = 16        # MS1+MS2 jumpered high on TMC2209 (see roadmap notes)
REDUCTION = 3.0       # 20T -> 60T belt
STEPS_PER_RAD = FULL_STEPS * MICROSTEP * REDUCTION / (2 * math.pi)  # ~1527.9

# flip these if a joint moves backwards at bench test:
JOINT_SIGN = (1, 1)

ELBOW = +1            # elbow configuration (+1 or -1); one config covers A5

# --- motion -------------------------------------------------------------------
DRAW_FEED = 30.0      # mm/s with pen down
TRAVEL_FEED = 80.0    # mm/s pen up
POINT_SPACING = 0.6   # mm between interpolated points
MIN_PERIOD_US = 200   # never step faster than 5 kHz
SEG_MIN_MS = 8

# --- homing pose ----------------------------------------------------------------
# v1 has NO limit switches and NO StallGuard (that needs UART+DIAG; we only
# wired STEP/DIR/EN). Homing is 100% MANUAL every power-cycle:
#   1. By hand, rotate both joints until the arm rests against its printed
#      alignment stops (the "parked" pose).
#   2. Send "H" to the firmware -> it zeros its step counters to HOME_ANGLES.
#   3. Only then run a drawing. If the arm gets bumped or loses steps
#      mid-session, re-home before trusting positions again.
# Upgrade path (not built): 2 microswitches on GPIO for auto-homing, or
# free up 2 more GPIO for UART+DIAG to use StallGuard sensorless homing.
HOME_ANGLES = (0.0, 0.0)

PORT = "COM3"         # Pico's port (Device Manager); override with --port


def sheet_to_world(u, v):
    """Sheet coords (u along 210mm width, v along 148mm, origin center)
    -> world mm at the shoulder. Sheet width lies along world Y."""
    return (PAPER_CX + v, u)

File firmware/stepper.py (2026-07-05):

# PIO step generator — one state machine per joint.
#
# WHY PIO: drawing needs step pulses at up to ~5000/sec with metronome timing.
# Python can't promise that; the Pico's PIO hardware state machines can.
# Each motion segment hands the SM two numbers: (pulse count, pulse period).
# The SM then emits exactly `count` pulses spaced exactly `period` apart,
# in silicon, unaffected by anything Python is doing.
#
# The DIR pin is ordinary GPIO: Python sets direction BETWEEN segments
# (the executor waits for the SM to finish before changing it).

import rp2
from machine import Pin

SM_FREQ = 1_000_000          # 1 MHz -> delay units of 1 microsecond


@rp2.asm_pio(set_init=rp2.PIO.OUT_LOW, autopull=False)
def _step_program():
    pull(block)              # word 1: pulse count - 1  -> x
    mov(x, osr)
    pull(block)              # word 2: low-time in us   -> saved in isr
    mov(isr, osr)
    label("pulse")
    set(pins, 1) [3]         # STEP high ~4us (TMC2209 needs >0.1us)
    set(pins, 0)
    mov(y, isr)              # reload the period
    label("dly")
    jmp(y_dec, "dly")        # burn `low-time` microseconds
    jmp(x_dec, "pulse")      # next pulse until count exhausted


class StepChannel:
    """One joint: STEP via PIO, DIR via GPIO."""

    def __init__(self, sm_id, step_pin, dir_pin):
        self.dir_pin = Pin(dir_pin, Pin.OUT, value=0)
        self.sm = rp2.StateMachine(sm_id, _step_program,
                                   freq=SM_FREQ, set_base=Pin(step_pin))
        self.sm.active(1)
        self.position = 0            # signed step counter (our odometry)
        self._pending = 0
        self._dir = 1

    def busy(self):
        # SM is done when both FIFO words were consumed AND the last
        # pulse train had time to finish; tx_fifo() covers the queue part.
        return self.sm.tx_fifo() > 0

    def start_segment(self, steps, period_us):
        """Fire `abs(steps)` pulses, sign = direction. Non-blocking."""
        if steps == 0:
            return
        self._dir = 1 if steps > 0 else -1
        self.dir_pin.value(1 if steps > 0 else 0)
        n = abs(steps)
        self.sm.put(n - 1)
        self.sm.put(max(2, int(period_us) - 6))   # -6: loop overhead cycles
        self._pending = n

    def finish_segment(self):
        """Call after the segment's time has elapsed: book the steps."""
        self.position += self._dir * self._pending
        self._pending = 0

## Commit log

2026-07-03 Balance Bot: project kickoff — plan, parts, phases
2026-07-03 SCARA Drafter: full project plan
    Repurposes this repo (was balance-bot kickoff) for the chosen project: a
    3D-printed SCARA arm that drafts Onshape DXF exports on A5 paper. Adds
    README (architecture + demo loop), roadmap (phases 0-5 with milestone
    ladders and the one-clean-square rule), vetted ~$160 shopping list,
    decisions D1-D7, risks R1-R7, and the debugging log template.
2026-07-03 Pressure-test fixes: belt-first design rule, power architecture, wiring limits
    - D9/roadmap: link and base CAD now waits for measured belts (closed-loop
    GT2 lengths dictate joint center distances); 60T pulleys explicitly printed
    - D8: 12V motors-only, USB powers Pico+servo (no buck needed), motor coil
    current never routed through breadboard rails
    - R8: breadboard current limit + 100uF cap placement
    - Shopping list: belt kit spec pinned to 2GT-200 closed loops, 5mm-bore 20T
2026-07-03 Simplify bearings: both joints use identical 608 + M8 axle stack
    One joint pattern built twice (drops the 625 bearing size); M8x50 bolts
    + nyloc nuts added to the cart as joint axles.
2026-07-03 Add concept render (OpenSCAD mockup) as README hero image
    [concept-mockup.scad]
2026-07-03 Real printable parts v1: base, arms, 60T pulley-hubs, carriage, spacers
    Parametric OpenSCAD part set with STL exports and renders. One hub design
    serves both joints (flipped for the elbow). Belt center distance (58.6mm
    nominal for 2GT-200) and press-fit tolerances remain parameters, finalized
    after parts arrive per D9 and the bearing coupon.
    [arm1.stl, arm2.stl, base.stl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]
2026-07-03 Parametrize pen bore for the MUJI gel knock-type 0.5 pen
    PEN_D parameter (measure barrel, set measured+0.4); slit doubles as
    clip clearance. Carriage STL re-exported at 11.0 nominal.
    [scara-parts.scad]
2026-07-03 Re-export carriage STL with MUJI pen bore
    [carriage.stl]
2026-07-04 Fix two assembly clashes caught by the labeled-diagram audit
    - Base deck gets a pass-through cutout: shoulder motor body no longer
    collides with the deck (motor hangs from the platform through it)
    - Platform wall gap widened 42.0 -> 44mm to actually fit a NEMA17 body
    - Assembly view now includes bought components (motors, pulleys, belts,
    servo, pen, paper, electronics); component render added
    [scara-parts.scad]
2026-07-04 Re-export base STL with clash fixes
    [base.stl]
2026-07-04 Fix hub bearing-seat print failure: chamfer the internal ring bridge
    The pocket-to-bore transition was an unsupported circular bridge and
    printed stringy. Now a 1mm seat ring + 45-degree self-supporting cone.
    Logged in the debugging log; hub.stl re-exported.
    [scara-parts.scad]
2026-07-04 Hub print fix, round 2: eliminate ALL ring overhangs
    Bottom pocket transition is now a full 45-degree cone (no flat, no
    bridging) with a drop-in seat washer added to spacers.stl to restore the
    bearing flat face. Top belt flange gets a cone underneath. Debugging log
    updated with the round-2 lesson: sweep the whole part for a failure mode,
    not just the first instance.
    [scara-parts.scad, spacers.stl]
2026-07-05 Fix shoulder axle: hex pocket moved to tower top (M8x50 reach)
    Bottom-pocketed head required an ~85mm bolt across deck+tower+hub stack;
    top pocket needs only 44mm of shank, matching the elbow pattern and the
    purchased M8x50 bolts. Caught in final pre-order hand audit.
    [base.stl, scara-parts.scad]
2026-07-05 Full software stack: firmware + PC pipeline, all tests passing
    Firmware (MicroPython/Pico W): PIO step generation (count+period per
    segment), coordinated 2-axis queue, active-low EN handling, pen servo,
    estop, silence watchdog. Host-simulated 9/9 (found and fixed a stale
    pen-state bug in estop via the sim).
    PC software (Python): 2-link IK (2000-point roundtrip < 1e-9), path
    planner with step-residual carry and 5kHz rate cap, ezdxf-based DXF
    loader with sheet fitting, serial link with flow control + watchdog
    feeding, calibration-square and draw-dxf tools. Self-test 10/10.
    [draw_dxf.py, draw_square.py, dxf_loader.py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]
2026-07-06 Clarify manual homing procedure; flag servo VBUS brownout risk
    Homing was implicit (park at printed stops, send H) - now explicitly
    documented as fully manual, no switches/StallGuard in v1, with an upgrade
    path noted. Added a bench-note for a subtle risk: MG90S stall current on
    the Pico's raw VBUS rail could brown out the board; documented the symptom
    and two fixes (buffer cap or separate 5V reg) before it bites during bench
    testing.
    [scara_config.py]
2026-07-06 Prove arm2/tower clearance: numeric check + real IK-driven sweep animation
    Parametrized J1/J2 in scara-parts.scad's assembly view (plain overridable
    vars, not $t - OpenSCAD 2021.01's --animate hits a Windows GL context bug
    across many frames in one process, and $t isn't reliably overridable via
    -D anyway).
    cad/clearance_check.py numerically verifies arm2's swept body (a tapered
    capsule, not a thin line) against the base tower's frustum radius, across
    every reachable point on the usable A5 sheet (3721-point grid, 0 unreachable).
    Worst case: pen at the paper's near edge, arm2 folded to 156 degrees -
    12mm clearance. Confirmed CLEAR, not just eyeballed.
    docs/img/workspace-sweep.gif: 32 frames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
    [scara-parts.scad]
2026-07-06 Bench Day 1: log the servo bring-up debugging saga
    First real hardware milestone: firmware confirmed on real Pico W silicon,
    servo wired and moving on command. Logged the VBUS misidentification bug
    (photo-counting vs. physical landmark + live measurement) - a genuine
    multi-step debugging story, not a one-liner.
2026-07-06 Split hub bearing pocket tolerance per side (bottom vs top)
    Bench test 2026-07-06: bottom pocket (printed near the bed) came out
    snug, top pocket (printed higher, near the arm boss) came out loose -
    normal FDM print variance between early and late layers, not a design
    error. Parametrized BRG_OD into BRG_OD_BOT/BRG_OD_TOP so the second
    hub print (still needed) can be tuned to match on both sides. Top
    shrunk 22.3 -> 22.1mm as a first pass.
    [scara-parts.scad]
